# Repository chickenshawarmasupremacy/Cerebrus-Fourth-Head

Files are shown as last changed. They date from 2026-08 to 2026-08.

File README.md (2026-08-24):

circuit_image
Cerebrus-Fourth-Head

A multi-servo robotic arm/head platform built around an ESP32, with a separate high-current power rail for driving seven mixed-type servos. Built for learning, and as a base for later work with AI models, ROS 2, and Gazebo.

Table of Contents
Hardware
Power Architecture
Bill of Materials
Wiring Diagram
CAD
Firmware
Repository Notes
Status
Roadmap
License
Hardware
Controller: ESP32
Actuators: 7 servos (mixed types) — 3x MG90S, 3x MG996R, 1x DS3218
Power supply: Toshiba buck converter (servo rail), separate from the ESP32 logic rail
Wiring: Hand-wired on perf board, AWG gauge selected per rail current draw
Previous revision: HW-131 buck converter. Replaced because its input voltage headroom was too low, which caused rail sag under load and torque loss during current spikes.
Power Architecture

The ESP32 logic supply is electrically separate from the servo power rail. This avoids brownouts and logic glitches when servos draw current spikes.

Traced the original torque loss to insufficient regulator headroom (AMS1117 limitations) on the old power path.
Evaluated parallel buck converter configurations with current-sharing resistors to cover peak current across all seven servos.
Sized wire gauge (AWG) per branch based on expected continuous and peak current, not total system current.
Bill of Materials

Full BOM with purchase links: BOM.csv. A few rows (buck converter part number, connector types, wire gauge) are still being finalized.

Wiring Diagram

https://app.cirkitdesigner.com/project/4b6c4f35-8d81-41e9-b8f0-a50af25d7959

An interactive version of this circuit is also maintained on Cirkit Designer.

CAD
Native CAD source (Fusion 360): https://a360.co/4wOWuL7
Shapr3D: https://app.shapr3d.com/p/7f951f56-316d-4975-8dc6-9f119cc89c82
STEP exports: models/
Firmware

Targets the ESP32, built with PlatformIO and the Arduino framework.

Requirements
PlatformIO Core or the PlatformIO IDE extension for VS Code
USB cable capable of data transfer (not charge-only)
ESP32 board drivers installed (CP210x or CH340, depending on the board)
Build
bash
# from the firmware project root (where platformio.ini lives)
pio run
Flash
bash
# connect the ESP32 via USB, then:
pio run --target upload

# if the port isn't auto-detected, specify it explicitly:
pio run --target upload --upload-port /dev/ttyUSB0   # Linux
pio run --target upload --upload-port COM5            # Windows
Monitor serial output
bash
pio device monitor

If upload fails, hold the BOOT button on the ESP32 while the upload starts. Some boards need this to enter flashing mode.

Repository Notes
.gitignore excludes VS Code IntelliSense cache files (browse.vc.db and related).
Git history was cleaned via interactive rebase to remove previously committed cache bloat.

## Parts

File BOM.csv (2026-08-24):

Category | Item | Qty | Specification / Notes | Suggested Purchase Link
Controller | ESP32 Dev Board | 1 | ESP32-WROOM-32 (or equivalent), used for servo control logic | https://www.digikey.com/en/products/detail/espressif-systems/ESP32-DEVKITC-32E/9356990
Actuator | MG90S Micro Servo | 3 | 1.8-2.2kg/cm torque, 4.8-6V, metal gear | https://www.amazon.com/Turnigy-MG90S-Digital-Metal-0-10sec/dp/B00URCIQGQ
Actuator | MG996R Standard Servo | 3 | ~13-15kg/cm torque, 4.8-6V, metal gear | https://www.amazon.com/Hosyond-MG996R-Digital-Motors-Helicopter/dp/B0BYD9M1P3
Actuator | DS3218 High-Torque Servo | 1 | 20kg/cm torque, 270°, waterproof, metal gear | https://www.amazon.com/DS3218-Digital-Control-Waterproof-Degrees/dp/B0GQM8KZ7B
Power | Toshiba Buck Converter | 1 | Fill in exact part number and input/output voltage + current rating | https://www.digikey.com/en/products/filter/dc-dc-switching-regulators/74
Power | 12V to 5V Buck Converter Module | 1 | 15A, wire-lead interface, steps 12V rail down to 5V logic supply | https://www.amazon.com/Converter-Voltage-Module-Supply-DCCON-C15/dp/B00BN369SA
Power | 9V Battery Clip Connector | 2 | I-type snap connector, wire leads | https://www.amazon.com/LBTODH-Battery-Connector-Flexible-Plastic/dp/B092TG1TSQ
Power | AA Battery Holder (4-slot) | 1 | 4x AA holder with wire leads, 6V output | https://www.amazon.com/LAMPVPATH-Battery-Holder-Leads-Wires/dp/B07T7MTRZX
Wiring | Hookup wire (~1m) | 1 | 22 AWG solid-core hookup wire kit, 6 colors, ~30ft/spool - cut to length as needed | https://www.amazon.com/TUOFENG-Hookup-Wires-6-Different-Colored/dp/B07TX6BX47
Wiring | ELEGOO Dupont Jumper Wire Pack | 1 | 120pcs multicolored M-F/M-M/F-F breadboard jumper wires | https://www.amazon.com/Elegoo-EL-CP-004-Multicolored-Breadboard-arduino/dp/B01EV70C78
Wiring | Perf board | 1 | Fill in board size used | https://www.adafruit.com/product/2670
Mechanical | PLA+ Filament (500g used) | 1 | ELEGOO PLA+ 1.75mm, 1kg spool (smallest standard size - ~500g needed for this build) | https://www.amazon.com/ELEGOO-Filament-Toughness-Dimensional-Accuracy/dp/B0D41ZDC47

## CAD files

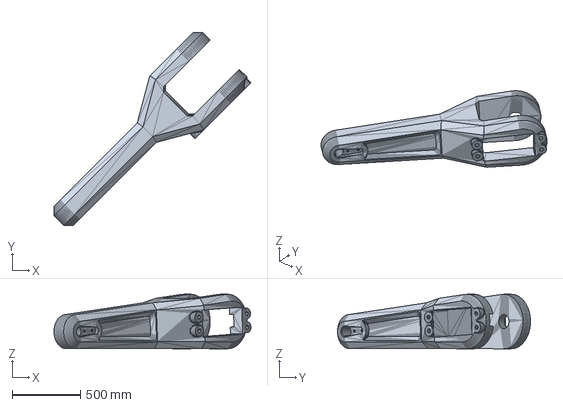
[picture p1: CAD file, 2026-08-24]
indivdualCADfiles/Arm_edit.step
1445.2 x 1416.3 x 400.0 mm

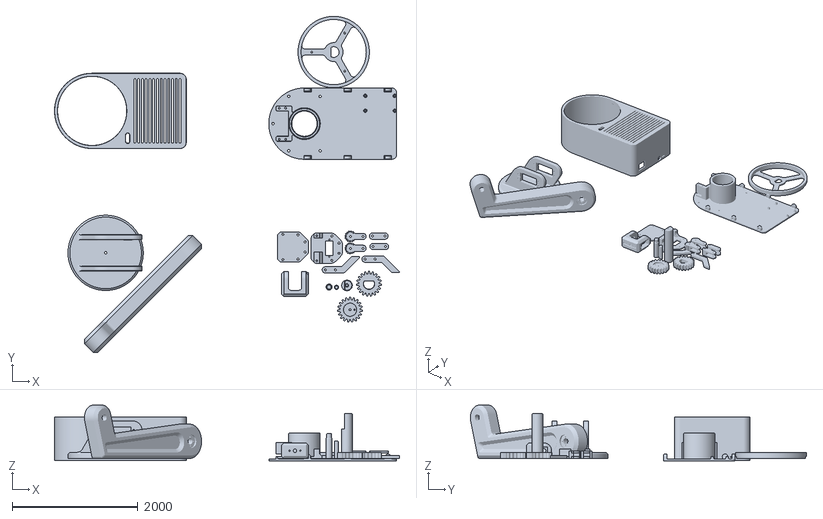
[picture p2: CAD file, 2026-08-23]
Robotic_Arm_With_ESP32.stl
5495.6 x 5356.5 x 889.8

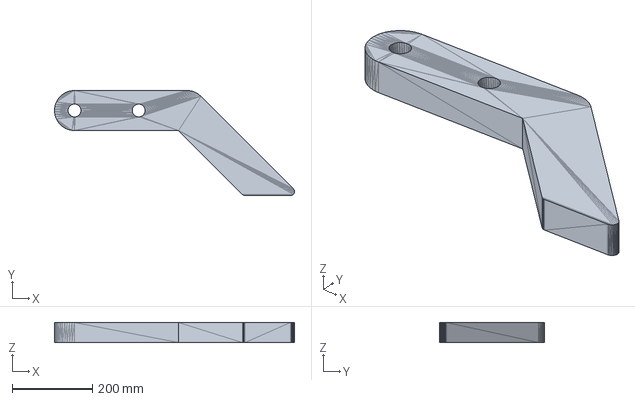
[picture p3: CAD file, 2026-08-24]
indivdualCADfiles/MeshBody1 (19).step
598.6 x 262.1 x 50.0 mm

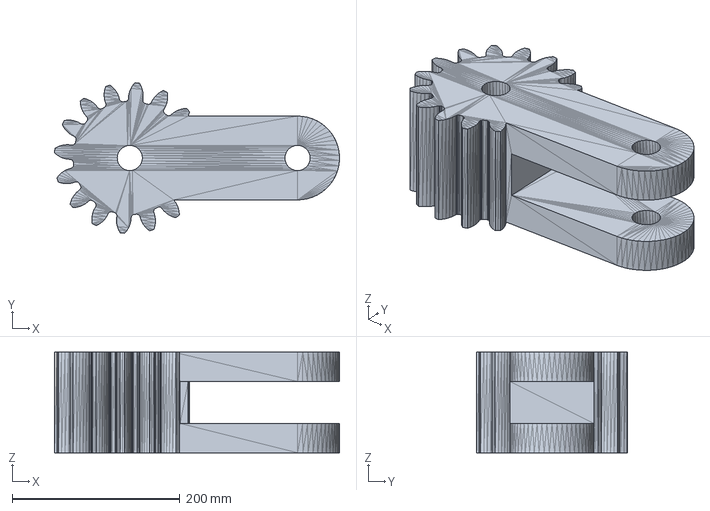
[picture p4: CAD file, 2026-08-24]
indivdualCADfiles/MeshBody1 (20).step
339.8 x 179.6 x 120.0 mm

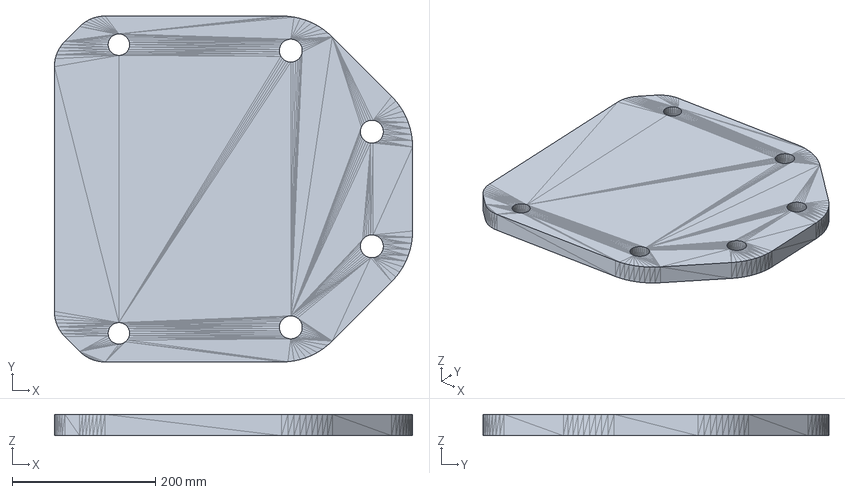
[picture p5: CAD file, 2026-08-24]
indivdualCADfiles/MeshBody1 (14).step
500.0 x 482.8 x 30.0 mm

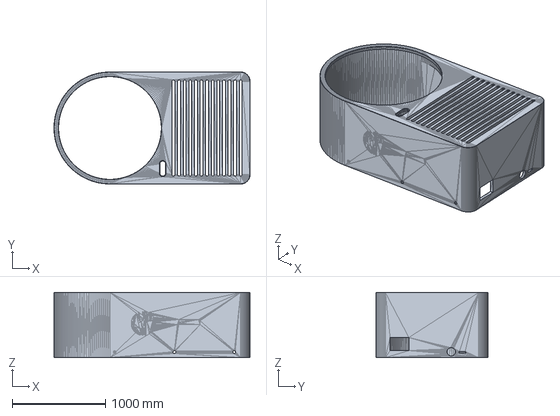
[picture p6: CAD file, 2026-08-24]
indivdualCADfiles/MeshBody1.step
2099.9 x 1200.0 x 700.0 mm

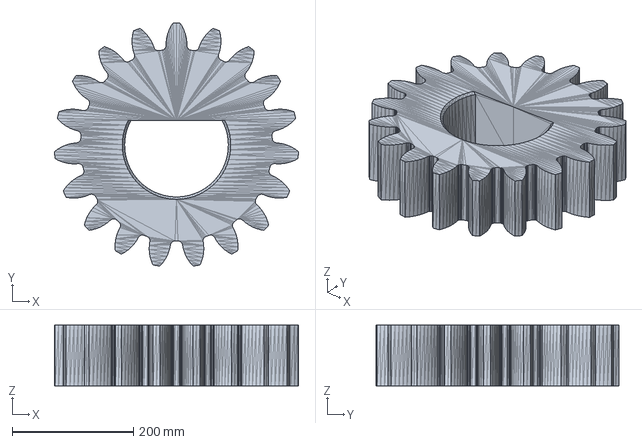
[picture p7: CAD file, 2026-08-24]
indivdualCADfiles/MeshBody1 (10).step
402.6 x 401.3 x 100.0 mm

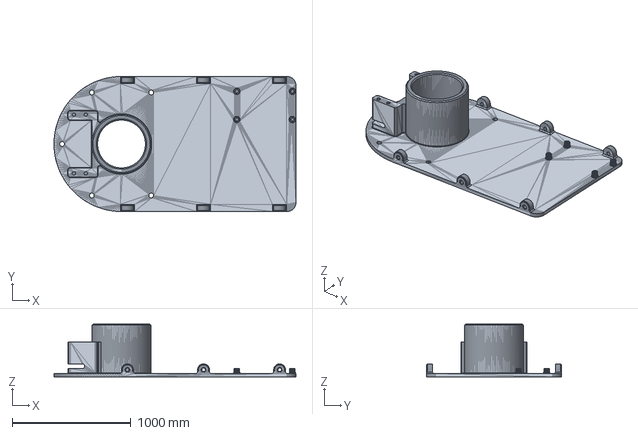
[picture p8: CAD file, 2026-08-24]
indivdualCADfiles/WorkthatBody.step
2036.0 x 1136.0 x 445.0 mm

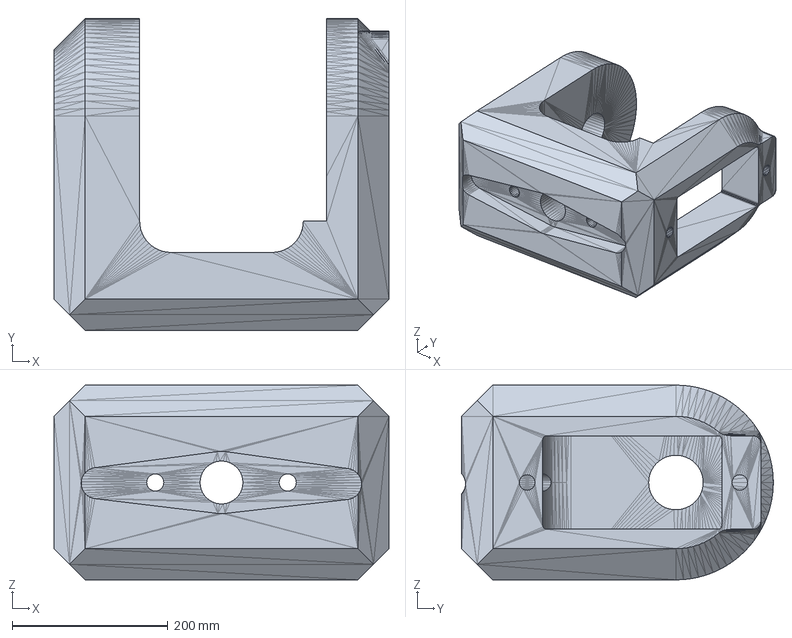
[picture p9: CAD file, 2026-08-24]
indivdualCADfiles/fixedClamperModel.step
430.0 x 400.0 x 250.0 mm

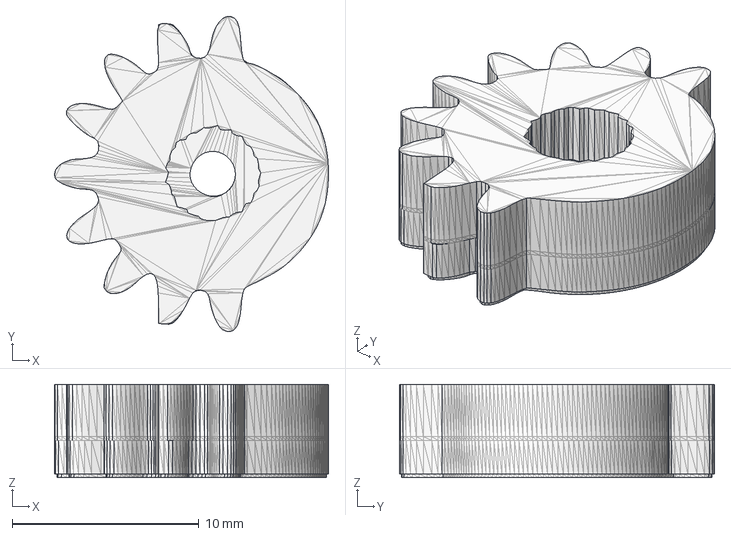
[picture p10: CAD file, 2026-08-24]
indivdualCADfiles/Edited_gear.step
14.7 x 16.9 x 5.00 mm

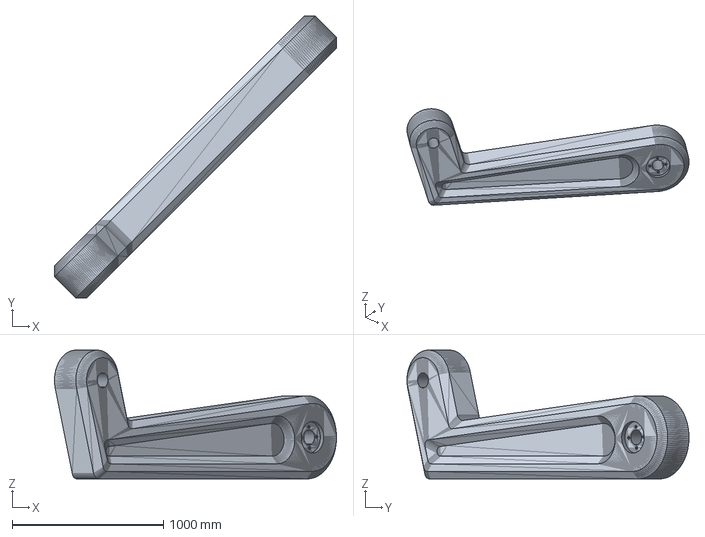
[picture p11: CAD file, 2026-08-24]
indivdualCADfiles/meshBody2.step
1866.1 x 1866.1 x 852.3 mm

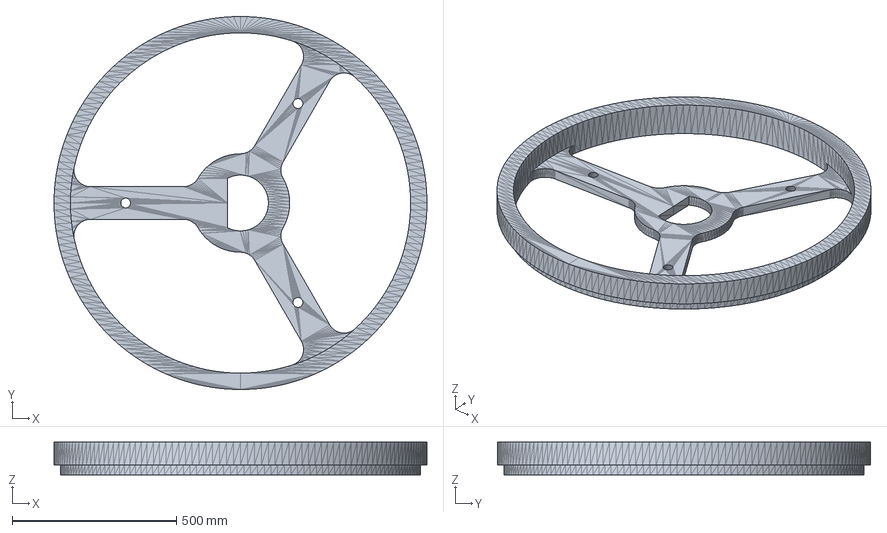
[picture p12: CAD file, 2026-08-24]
indivdualCADfiles/MeshBody1 (22).step
1137.0 x 1137.0 x 100.0 mm

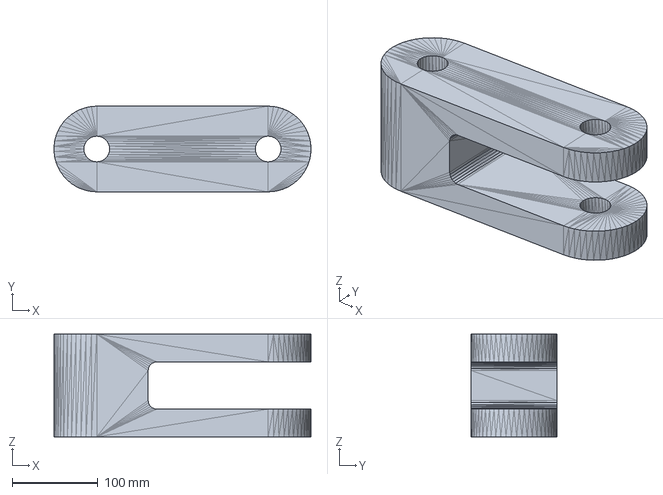
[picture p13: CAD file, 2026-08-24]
indivdualCADfiles/MeshBody1 (16).step
299.9 x 100.0 x 120.0 mm

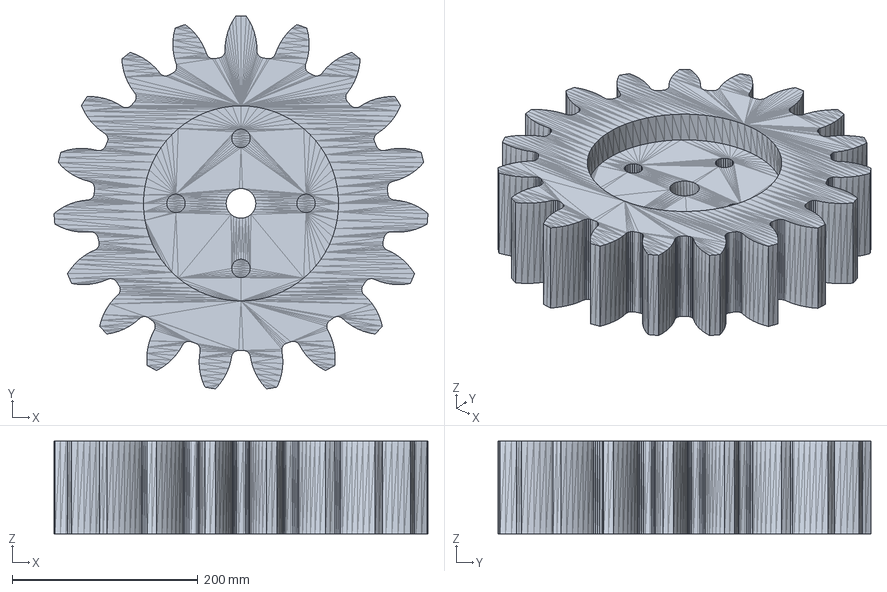
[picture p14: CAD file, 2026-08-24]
indivdualCADfiles/MeshBody1 (12).step
402.6 x 401.3 x 100.0 mm

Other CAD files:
indivdualCADfiles/MeshBody1 (18).step
indivdualCADfiles/MeshBody1 (15).step
indivdualCADfiles/MeshBody1 (17).step
indivdualCADfiles/Edited_gear.3mf (1).step
indivdualCADfiles/MeshBody1 (2).step
indivdualCADfiles/MeshBody1 (21).step
indivdualCADfiles/MeshBody1 (7).step
indivdualCADfiles/MeshBody1 (8).step
indivdualCADfiles/MeshBody1 (9).step

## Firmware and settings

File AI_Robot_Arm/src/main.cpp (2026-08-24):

/* Code written by Izyan Khan
Simple robot arm control
*/


#include <Arduino.h>
#include <Servo.h>


//Servo declarations are here(Important to note: Servo is a data type)
Servo clamper;
Servo myServo2;
Servo myServo3;
Servo myServo4;
Servo myServo5Link;
Servo myServo6Link;
Servo rotator;

void moveServo(Servo &motor, int angle, int minAngle = 0, int maxAngle = 180) {
  int currentAngle = motor.read();
  int newAngle = currentAngle + angle;

  // Ensure the new angle is within the specified range
  if (newAngle < minAngle) {
    newAngle = minAngle;
  } else if (newAngle > maxAngle) {
    newAngle = maxAngle;
  }

  motor.write(newAngle);
}


void  setup() {
  //Attaching all servo motors to their respective pins here
  Serial.begin(115200);

  // Attach all servos to their pins
  clamper.attach(32);
  clamper.write(0);
  myServo2.attach(33);
  myServo2.write(0);
  myServo3.attach(25);
  myServo3.write(0);
  myServo4.attach(26);
  myServo4.write(0);
  myServo5Link.attach(27);
  myServo5Link.write(0);
  myServo6Link.attach(14);
  myServo6Link.write(180);
  rotator.attach(12);

  // Initial positions
  clamper.write(0);
  myServo2.write(90);
  myServo3.write(90);
  myServo4.write(90);
  myServo5Link.write(90);
  myServo6Link.write(90);
  rotator.write(90);
}

void loop() {
  if (Serial.available() > 0) {
    char controller = Serial.read();

    switch (controller) {
      case ' ':
        if (clamper.read() == 0) {
        moveServo(clamper, 90, 0, 90); // Open the clamper
        } else {
          moveServo(clamper, -90, 0, 90); // Close the clamper
        }
        break;

      case 'w':
        moveServo(myServo2, 15);
        break;

      case 's':
        moveServo(myServo2, -15);
        break;

      case 'a':
        moveServo(myServo3, 15);
        break;

      case 'd':
        moveServo(myServo3, -15);
        break;

      case 'q':
        moveServo(myServo4, 15);
        break;

      case 'e':
        moveServo(myServo4, -15);
        break;
//Not using the moveServo command here to fix the issue of two seros being connected to drive the same joint.
      case 'z':
        if (myServo5Link.read() < 166) {
          int tempAngle = myServo5Link.read() + 15;
          myServo5Link.write(tempAngle);
          myServo6Link.write(180 - tempAngle);
        }
        else {
          myServo5Link.write(180);
          myServo6Link.write(0);
        }
        break;
      case 'v':
        if (myServo5Link.read() > 15) {
          int tempAngle = myServo5Link.read() - 15;
          myServo5Link.write(tempAngle);
          myServo6Link.write(180 - tempAngle);
        }
        else {
          myServo5Link.write(0);
          myServo6Link.write(180);
        }
        break;

      case 'r':
        moveServo(rotator, 15);
        break;

      case 'f':
        moveServo(rotator, -15);
        break;

      default:
      Serial.println("Invalid command received");
        break;

    }
  }
}
>>>>>>> 5c21d05 (Semi final commit, wifi capabilities need to be added)

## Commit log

2026-08-02 Setting servos to 90
2026-08-23 Added the 3D Model File
    [Robotic_Arm_With_ESP32.stl]
2026-08-23 Enhance README with detailed project information
    Expanded project overview, hardware details, and power architecture information for the Cerebrus-Fourth-Head robotic arm.
2026-08-23 Enhance README with comprehensive project details
    Expanded the README to include detailed sections on hardware, power architecture, bill of materials, wiring diagram, CAD, firmware, and repository notes.
2026-08-23 Create BOM.csv with component details
    Added a Bill of Materials (BOM) with components, specifications, and purchase links.
    [BOM.csv]
2026-08-24 Enhance CAD section with download links
    Updated CAD section with links to Fusion 360 and Shapr3D.
2026-08-24 CAD files uploaded individually in step format
    [Arm_edit.step, Edited_gear.3mf (1).step, Edited_gear.step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]
2026-08-24 Revise README for clarity and updated specifications
    Updated project description for clarity and conciseness. Revised hardware specifications and BOM details. Improved formatting and removed redundant information.
2026-08-24 Add Arduino and Servo library includes
